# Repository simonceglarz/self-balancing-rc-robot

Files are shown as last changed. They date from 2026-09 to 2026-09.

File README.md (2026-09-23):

# ESP32 Self-Balancing Robot

A two-wheeled self-balancing robot built around an ESP32, an IMU, and a cascaded PID control loop — with a live WiFi tuning interface and a dedicated wireless joystick controller.

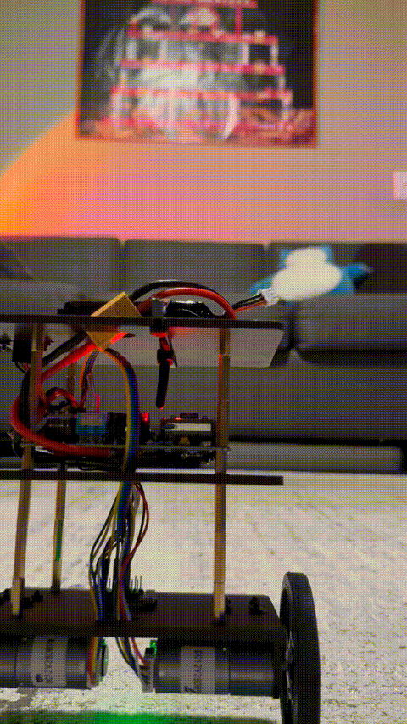
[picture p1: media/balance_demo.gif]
demo

   [Full-length demo (27s, MP4)](media/balance_full.mp4)
## Overview

This robot balances on two wheels using a complementary filter for orientation estimation and a two-loop (cascaded) PID controller: an inner loop holds the body upright, and an outer loop corrects for long-term drift by tracking wheel velocity from quadrature encoders. It can be driven and steered two ways — a phone/browser joystick served directly from the robot's own WiFi access point, or a dedicated physical ESP32 + analog-joystick controller communicating over ESP-NOW.

## Features

- **Cascaded PID control** — inner loop (angle) + outer loop (velocity/drift), tuned live rather than by reflashing
- **WiFi live-tuning webpage** — the ESP32 hosts its own access point and a WebSocket-driven page with sliders for every gain, calibration constant, and per-motor floor, plus a draggable on-screen joystick for driving
- **Physical joystick controller** — a second ESP32 reading an analog joystick, sending continuous steering data over ESP-NOW (no phone required, lower latency than WiFi)
- **Per-motor stiction compensation** — independently tunable output floors and a proportional rescale, since the two motors' real-world behavior isn't identical
- **Hysteresis-based deadband** — a Schmitt-trigger style engage/disengage threshold to suppress motor chatter at equilibrium without losing responsiveness to small corrections
- **Smoothly ramped inputs** — commanded lean/steer values slew toward their target instead of stepping instantly, avoiding derivative-kick spikes
- **OLED live telemetry** — angle, motor output, encoder-derived velocity, battery voltage, and a small tilt-indicator graphic

## Hardware

| Component | Notes |
|---|---|
| ESP32 dev board (x2) | one for the robot, one for the joystick controller |
| Adafruit LSM6DSOX | 6-axis IMU (accelerometer + gyro) |
| SSD1306 OLED (128x64, I2C) | onboard telemetry display |
| 2x DC motor + quadrature encoders | drive + odometry |
| Motor driver (dual H-bridge) | AIN1/AIN2, BIN1/BIN2 control |
| 2-axis analog joystick module | physical controller input |
| LiPo battery + voltage divider | robot power + monitoring via `analogReadMilliVolts()` |
| Buck regulator (Adafruit MPM3610, 5V) | steps the 7.4V 2S LiPo down to 5V for the ESP32 |
| Reverse-polarity protection (1N5822 Schottky) | sits ahead of the buck input, ~0.35V drop |

## Build

| | |
|---|---|
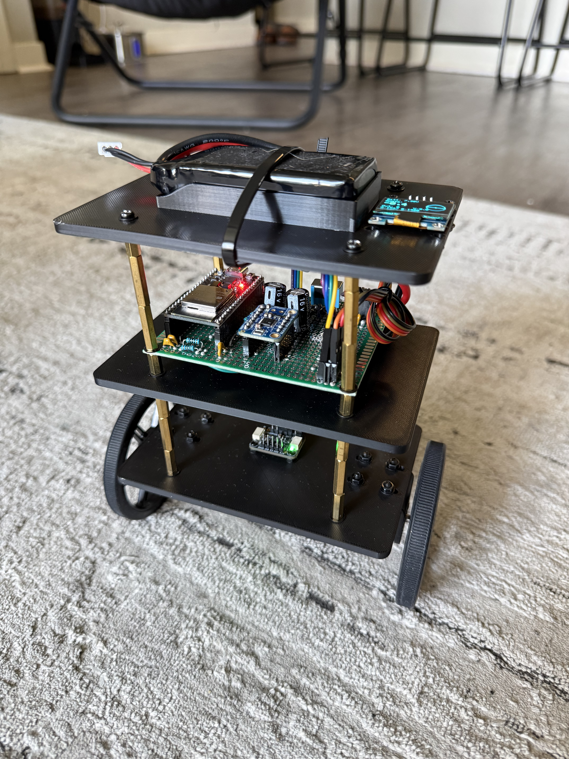
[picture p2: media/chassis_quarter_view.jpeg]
Full assembled chassis
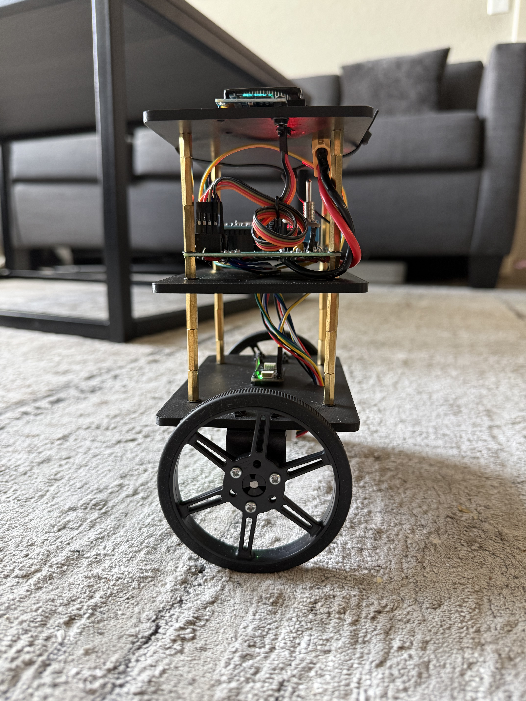
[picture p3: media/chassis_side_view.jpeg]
Inter-layer wiring detail
|  |  |
| Assembled 3-layer 3D-printed chassis — top plate carries the LiPo battery and OLED, middle plate holds the ESP32, IMU, and perfboard wiring, bottom plate mounts the motor driver. Brass standoffs separate the layers. | Rear view showing inter-layer wiring and one of the two drive wheels. |

## Architecture

```
IMU (accel + gyro) ──► complementary filter ──► angle estimate
                                                     │
                          ┌──────────────────────────┘
                          ▼
              inner loop: PID(Kp, Ki, Kd) on angle error
                          │
              outer loop: velocity/drift correction
              (encoder-derived velocity → Kp_vel/Ki_vel → shifts
               the angle setpoint to correct long-term drift)
                          │
                          ▼
        per-motor floor rescale + hysteresis deadband
                          │
                          ▼
                   motorA() / motorB() (PWM)
```

Input arrives from either the WebSocket ('J:x:y' from the webpage joystick, or discrete gain/calibration updates from the tuning sliders) or ESP-NOW (the physical joystick controller) — both write into the same `targetAngleTrim`/`steerBias` variables, so the control loop doesn't care which source is driving it.

## Power Architecture
2S LiPo (7.4V nominal, 8.4V full)
             │
             ▼
1N5822 Schottky diode (reverse-polarity protection, ~0.35V drop)
      │ 
      ▼
power node ──┬── DRV8833 VM (motors run off the unregulated battery rail)
             ├── 2× 1000µF bulk caps + 100nF ceramic → GND
             └── MPM3610 buck regulator (Vin)
                    │
                    ▼
               5V out → ESP32 5V pin
             │
             ▼
ESP32 internal LDO → 3.3V rail
	    │
┌───────────┼───────────┐
▼           ▼           ▼
IMU + OLED Encoder VCC DRV8833 SLP
   (I2C)     (must be held high or driver sleeps)

Motors draw directly off the unregulated battery rail (through the protection diode) since they don't need clean power; logic and sensors run off the regulated 5V → 3.3V chain, which does.

**Bench-verified (multimeter):**

| Measurement point | Reading |
|---|---|
| Diode cathode (post-protection) | 8.05 V |
| MPM3610 output | 5.00 V |
| ESP32 3.3V pin | 3.32 V |
| Battery rail under full motor load | 7.77 V (no sag — bulk caps holding) |

## Setup

Each firmware is its own PlatformIO project.

**Robot** (`robot/`):
1. `pio run --target upload` from within `robot/`
2. Power on, open the serial monitor (115200 baud) — it prints the WiFi AP IP and its ESP-NOW MAC address
3. Connect a phone/laptop to the `BalanceBot` AP and open `http://<AP IP>/` for the tuning page

**Controller** (`controller/`):
1. Wire the joystick module: VRx→GPIO34, VRy→GPIO35, SW→GPIO32, VCC→3.3V, GND→GND
2. Set `robotMac[]` in `controller/src/main.cpp` to the robot's printed AP MAC address
3. Confirm `WIFI_CHANNEL` matches between both projects
4. `pio run --target upload` from within `controller/`

Both projects are pinned to the same platform version (see each `platformio.ini`) — this matters, since ESP-NOW callback signatures changed between core versions and mismatched cores between the two boards can cause hard-to-diagnose link failures.

## Debugging notes / what I actually learned building this

- **Output floor destroyed proportionality.** A flat "snap any nonzero output up to the motor's stiction floor" made the controller bang-bang, not proportional, for the entire range under a few degrees of error — the majority of actual operating time. Fixed by rescaling the output range onto `[MIN_OUTPUT, MAX_OUTPUT]` per motor instead of snapping.
- **Encoder velocity math is a real kinematics problem, not an arbitrary sign choice.** Diagnosing whether `avgVelocity` should combine the two encoders by addition or subtraction meant understanding what each raw sign actually meant physically (translation vs. yaw), not just trying both and picking whichever "looked less bad." Verified empirically with a manual push test (motors disabled, print raw deltas) rather than guessing.
- **A control loop can have the wrong sign of an otherwise-correct formula.** Reversing the encoder combination made the outer loop feed real motion back into itself as *positive* feedback instead of negative — the difference between correcting drift and amplifying it into a runaway, from one flipped sign.
- **Deadbands need hysteresis, not a single threshold.** A flat deadband still has exactly one crossing point, and standing-still equilibrium sits right on top of it — sensor noise flickering across that single threshold was the actual jitter, not "too much" or "too little" deadband. A two-threshold (engage/disengage) hysteresis fixed it structurally instead of by tuning a magic number.
- **A hard on/off switch in a control loop creates a real discontinuity.** Suppressing the outer loop during a turn (to stop it reacting to a turn-induced phantom velocity reading) fixed the turn-tipping, but re-enabling it instantly the moment steering stopped caused a visible jerk — full-strength correction plus whatever stale value existed applied in a single tick. Replaced with a ramped suppression factor.

## Known limitations / open items

- `ANGLE_TRIM_DEG` (the sensor-to-mechanical zero offset) drifts somewhat run-to-run; auto-calibration was considered but not implemented.
- Turning still relies on suppressing the outer loop rather than a from-first-principles kinematic decoupling of translation and rotation.
- No IMU cross-axis leakage compensation (untested whether it's actually present on this build).

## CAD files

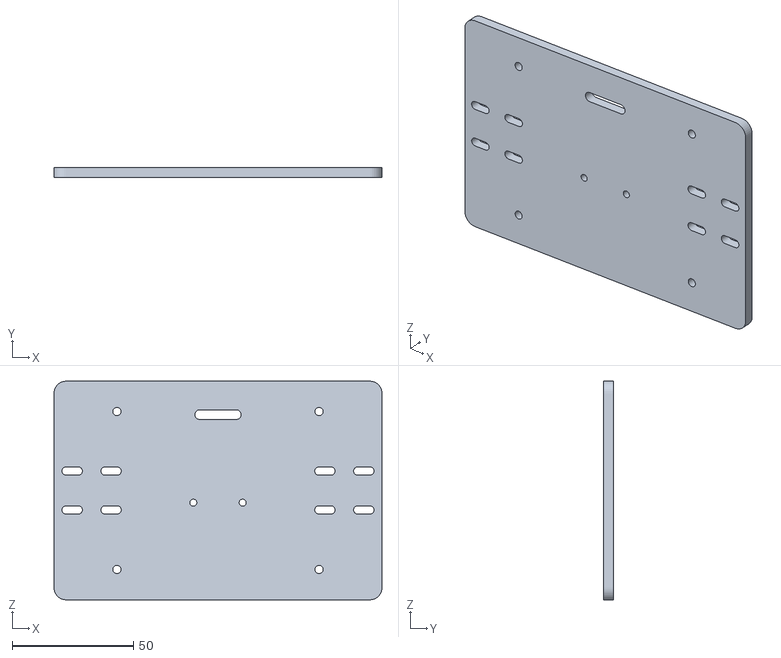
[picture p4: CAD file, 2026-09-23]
cad/chassis/bottom_plate.stl
135.0 x 4.00 x 90.0

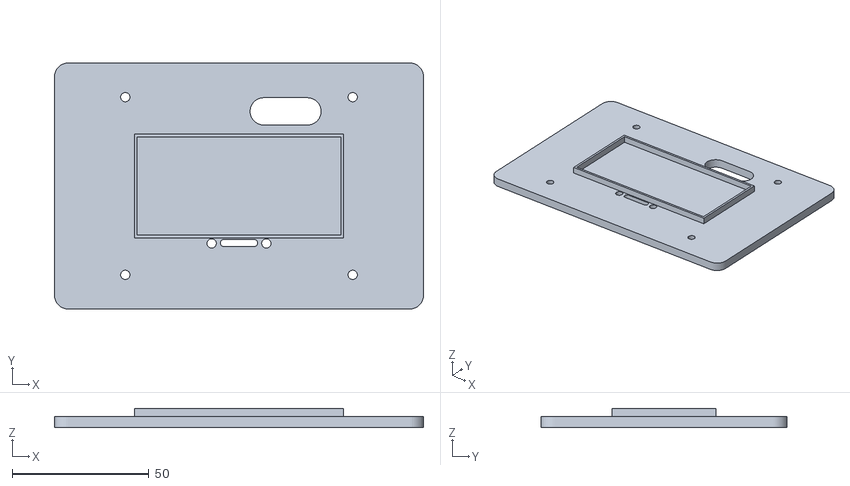
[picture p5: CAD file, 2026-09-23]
cad/chassis/top_plate_21552611.stl
135.0 x 90.0 x 7.00

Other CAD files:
cad/chassis/middle_plate.stl

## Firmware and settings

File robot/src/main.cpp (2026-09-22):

#include <Arduino.h>
#include <Wire.h>
#include <Adafruit_LSM6DSOX.h>
#include <Adafruit_SSD1306.h>
#include <Adafruit_GFX.h>
#include <WiFi.h>
#include <esp_now.h>
#include <ESPAsyncWebServer.h>

// =================== Pin map ===================
// GPIO19 = SDA, GPIO18 = SCL (confirmed against physical wiring).
#define SDA_PIN 19
#define SCL_PIN 18

// Motor driver — AIN1/AIN2 control Motor A, BIN1/BIN2 control Motor B.
#define AIN1 26
#define AIN2 32
#define BIN1 25
#define BIN2 33

// NOTE: arduino-esp32 core 3.0+ removed manual channel numbers —
// ledcAttach() below assigns a channel automatically per pin.

// Encoders — A-channel pins are the interrupt pins.
// GPIO 34/35 are input-only (no internal pull-up) — fine here,
// encoders are pure inputs. Can't be used for motor drive.
#define ENC_A1 27   // Motor A channel A
#define ENC_B1 14   // Motor A channel B
#define ENC_A2 34   // Motor B channel A
#define ENC_B2 35   // Motor B channel B

#define ENABLE_BATTERY_MONITOR 1
#if ENABLE_BATTERY_MONITOR
#define VBAT_PIN 36   // ADC1 — required, ADC2 dies when WiFi is active
const float VBAT_DIVIDER_RATIO = (100000.0 + 47000.0) / 47000.0; // 3.128
const float VBAT_CUTOFF = 6.6;
float lastVbat = 0.0;   // updated once/sec in loop(), read by the OLED block
#endif

// =================== Direction flags ===================
// Unknowns per project notes: mirror-mounted motors likely need one
// side's wires (or this flag) flipped; encoder sign is unverified
// until wheels actually turn. Flip these booleans after your first
// power-on test rather than rewiring or rewriting logic.
const bool INVERT_MOTOR_A = false;
const bool INVERT_MOTOR_B = true;   // confirmed via motor/encoder test — wheels now spin correctly
const bool INVERT_ENC_A   = false;
const bool INVERT_ENC_B   = false;

// Set to 1, flash, watch which physical wheel moves during each phase.
// Set back to 0 once you've identified A vs B and set the INVERT flags
// above — then reflash for real balancing.
#define RUN_MOTOR_ENCODER_TEST 0

// Set to 1 for a dead-simple sanity check: both motors spin together
// whenever the IMU detects real rotation, no matter which way the
// board is physically mounted. Good first test when you're not sure
// if motors OR the gyro are the actual problem.
#define RUN_BASIC_MOTOR_GYRO_TEST 0

// Set to 1 to run a bare I2C bus scan instead of normal setup — useful
// for diagnosing wiring without touching lib_deps/includes at all,
// since this reuses the exact dependency set that already builds fine.
#define RUN_I2C_SCANNER 0

#if RUN_I2C_SCANNER
void runI2CScanner() {
    Serial.println("I2C Scanner starting...");
    while (1) {
        byte count = 0;
        for (byte addr = 1; addr < 127; addr++) {
            Wire.beginTransmission(addr);
            byte error = Wire.endTransmission();
            if (error == 0) {
                Serial.print("Device found at address 0x");
                if (addr < 16) Serial.print("0");
                Serial.println(addr, HEX);
                count++;
            }
        }
        if (count == 0) Serial.println("No I2C devices found");
        else { Serial.print(count); Serial.println(" device(s) found"); }
        delay(3000);
    }
}
#endif

// =================== Objects ===================
Adafruit_LSM6DSOX sox;                          // IMU driver instance — talks to the
                                                 // physical sensor over I2C once Wire.begin() runs
Adafruit_SSD1306 display(128, 64, &Wire, -1);   // OLED driver — 128x64 px, shares the I2C bus
                                                 // with the IMU (-1 = no dedicated reset pin wired)

// Network name/password the ESP32 broadcasts. Since we're in AP mode,
// the ESP32 *is* the WiFi network — your phone connects to "BalanceBot"
// directly rather than both devices joining your home router.
const char* AP_SSID = "BalanceBot";
const char* AP_PASS = "tuning123";   // WPA2 requires 8+ characters minimum

// ESP-NOW (the physical joystick controller) and the AP (the tuning
// webpage) share the same radio, so they must agree on a channel — the
// controller firmware hardcodes this same value. If ESP-NOW packets
// silently never arrive, mismatched channel is the first thing to check.
const int WIFI_CHANNEL = 1;

AsyncWebServer server(80);
AsyncWebSocket ws("/ws");

// Must match the controller's JoyPacket struct byte-for-byte — ESP-NOW
// has no schema, it just copies raw bytes.
typedef struct {
    float x;   // -1 (left) .. +1 (right)
    float y;   // -1 (back) .. +1 (forward)
} JoyPacket;

// Shared with the webpage's 'J' WebSocket handler below, so both input
// sources command the same maximum lean/turn.
const float JOY_MAX_TRIM_DEG = 3.0;   // matches old FWD/BACK magnitude
const float JOY_MAX_STEER    = 30.0;  // matches old L/R magnitude

// =================== Live-tunable gains (WiFi) ===================
volatile float Kp = 38.0;
volatile float Ki = 0.7;
volatile float Kd = 0.4;
volatile float targetAngleTrim = 0.0;   // "goal" value set instantly by F/B commands —
                                         // the loop ramps toward this via
                                         // targetAngleTrimSmoothed rather than using
                                         // it directly, to avoid a derivative-kick step.
volatile float steerBias = 0.0;         // "goal" value set instantly by L/R commands —
                                         // same ramping treatment via steerBiasSmoothed.

// =================== Outer loop gains (WiFi-tunable via V/W) ===================
volatile float Kp_vel = 0.12;
volatile float Ki_vel = 0.003;

// =================== Filter / control state ===================
const float alpha = 0.98;

// Corrects for the IMU's zero-angle not lining up with the robot's true
// mechanical balance point (from mounting tilt, CoG offset, or both).
// Determine by trial and error: nudge this value up/down and re-test
// forward vs backward reaction thresholds until they're symmetric.
// Sign convention: if forward tilts react at SMALLER angles than
// backward tilts (as observed), try a small POSITIVE value first.
volatile float ANGLE_TRIM_DEG = -2.2;  // Tune live via the WiFi slider.
                             // The outer velocity loop can mask a wide
                             // range of trim error by continuously
                             // creeping to hold position, so "it balances"
                             // isn't proof a given value is correct —
                             // watch for steady creep in one direction
                             // at rest as the real symmetry check.

float angle = 0.0;
float lastAngle = 0.0;      // for derivative-on-measurement — see loop()
float gyroBias = 0.0;
float angleErrorIntegral = 0.0;
const float INTEGRAL_CLAMP = 100.0;
float velIntegral = 0.0;
const int MAX_OUTPUT = 255;

// Per-motor stiction floors — NOT assumed equal. Testing found motor A's
// physical wheel needs more duty to start turning than motor B's at all
// (at MIN=147, only B moved) — a single shared floor can't be correct for
// both without either stalling A or overdriving B. Tune live via WiFi.
volatile int MIN_OUTPUT_A = 146;
volatile int MIN_OUTPUT_B = 146;

// Per-motor output scale, applied across the WHOLE output range (not just
// near the floor) — corrects one motor consistently out-turning the other
// even away from the stiction region (observed: countB always ends up
// higher than countA over a run). Start both at 1.0 and nudge the FASTER
// motor's scale down while watching countA/-countB converge on the OLED.
volatile float MOTOR_A_SCALE = 1.0;
volatile float MOTOR_B_SCALE = 1.0;

const float FALL_CUTOFF_DEG = 45.0;

// Exponential-moving-average state for the encoder-derived velocity —
// see avgVelocityFiltered below. 0.1 is a starting guess, not a derived
// value: raise it (closer to 1.0) for less smoothing/more responsiveness,
// lower it for more smoothing if the outer loop still looks jumpy.
const float VEL_FILTER_ALPHA = 0.1;

// Max age, in seconds, that a single loop iteration's dt is allowed to
// have before being clamped. Without this, a loop iteration delayed by
// WiFi/WebSocket servicing (a genuinely occasional ESP32 async-server
// hiccup) produces one abnormally large dt, which inflates the integral
// term (error * dt) and shrinks the derivative denominator in the same
// tick — a plausible cause of the brief "controls give out" moments.
const float MAX_DT = 0.02;   // 20ms — 2x the normal ~10ms tick

// How fast targetAngleTrim/steerBias ramp toward their commanded value
// per second, instead of jumping instantly. Prevents the FWD/BACK/LEFT/
// RIGHT buttons from causing a one-tick derivative-kick-style spike and
// the overshoot/tipping that comes with it. Starting guesses — raise for
// snappier response, lower if it still feels like it overshoots.
const float TRIM_SLEW_PER_SEC  = 12.0;  // deg/sec
const float STEER_SLEW_PER_SEC = 80.0;  // units/sec (same units as steerBias)

// =================== Encoder state ===================
volatile long countA = 0;
volatile long countB = 0;
long lastCountA = 0, lastCountB = 0;

void IRAM_ATTR encA_ISR() {
    bool state = digitalRead(ENC_A1) == digitalRead(ENC_B1);
    if (INVERT_ENC_A) state = !state;
    if (state) countA++; else countA--;
}
void IRAM_ATTR encB_ISR() {
    bool state = digitalRead(ENC_A2) == digitalRead(ENC_B2);
    if (INVERT_ENC_B) state = !state;
    if (state) countB++; else countB--;
}

// =================== Motor drive ===================
void motorA(int speed) {
    if (INVERT_MOTOR_A) speed = -speed;
    speed = constrain(speed, -255, 255);
    if (speed >= 0) { ledcWrite(AIN1, speed); ledcWrite(AIN2, 0); }
    else            { ledcWrite(AIN1, 0); ledcWrite(AIN2, -speed); }
}
void motorB(int speed) {
    if (INVERT_MOTOR_B) speed = -speed;
    speed = constrain(speed, -255, 255);
    if (speed >= 0) { ledcWrite(BIN1, speed); ledcWrite(BIN2, 0); }
    else            { ledcWrite(BIN1, 0); ledcWrite(BIN2, -speed); }
}

// =================== Motor/Encoder identification test ===================
// Defined HERE (after motorA/motorB/countA/countB), not earlier — it
// references all of them. The actual CALL that runs this lives in
// setup(), further down.
#if RUN_MOTOR_ENCODER_TEST
void runMotorEncoderTest() {
    Serial.println("=== MOTOR/ENCODER TEST ===");
    Serial.println("Watch which physical wheel moves in each phase.");
    delay(2000);

    Serial.println("Testing Motor A (forward command)...");
    motorA(150);
    for (int i = 0; i < 15; i++) {
        Serial.print("  countA: "); Serial.println(countA);
        delay(100);
    }
    motorA(0);
    delay(1000);

    Serial.println("Testing Motor B (forward command)...");
    motorB(150);
    for (int i = 0; i < 15; i++) {
        Serial.print("  countB: "); Serial.println(countB);
        delay(100);
    }
    motorB(0);

    Serial.println("=== TEST COMPLETE ===");
    Serial.println("Whichever wheel moved during 'Motor A' phase IS Motor A.");
    Serial.println("If countA/countB didn't increase during its own phase,");
    Serial.println("that encoder's INVERT flag or wiring needs checking.");
    while (1) delay(1000);  // halt here — never falls through to balancing
}
#endif
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
void loop() {
    static unsigned long lastTime = 0;
    static unsigned long lastDisplay = 0;
    static unsigned long lastTelemetry = 0;
    static float avgVelocityFiltered = 0.0;      // smoothed encoder velocity — see VEL_FILTER_ALPHA
    static float targetAngleTrimSmoothed = 0.0;  // ramped toward targetAngleTrim — see TRIM_SLEW_PER_SEC
    static float steerBiasSmoothed = 0.0;        // ramped toward steerBias — see STEER_SLEW_PER_SEC
    static bool motorEngaged = false;            // hysteresis deadband state — see below
    static float turnSuppress = 0.0;             // 0 = full Kp_vel authority, 1 = fully suppressed — see below

    unsigned long now = millis();
    if (now - lastTime < 10) return;
    float dt = (now - lastTime) / 1000.0;
    lastTime = now;

    // Guard against a delayed loop iteration (e.g. WiFi/WebSocket
    // servicing) producing one abnormally large dt, which would
    // otherwise inflate the integral term and shrink the derivative
    // denominator in the same tick — see MAX_DT comment above.
    if (dt > MAX_DT) dt = MAX_DT;

    sensors_event_t accel, gyro, temp;
    sox.getEvent(&accel, &gyro, &temp);

    float accelAngle = atan2(accel.acceleration.y,
                             accel.acceleration.z) * 180.0 / PI - ANGLE_TRIM_DEG;
    float gyroRate = (gyro.gyro.x * 180.0 / PI) - gyroBias;

    angle = alpha * (angle + gyroRate * dt) + (1.0 - alpha) * accelAngle;

    // Ramp the commanded trim/steer toward their target values instead
    // of jumping instantly — avoids the derivative-kick-style spike a
    // step change would otherwise cause (see loop() notes below).
    float trimStep = TRIM_SLEW_PER_SEC * dt;
    if (targetAngleTrimSmoothed < targetAngleTrim) {
        targetAngleTrimSmoothed = min(targetAngleTrimSmoothed + trimStep, (float)targetAngleTrim);
    } else if (targetAngleTrimSmoothed > targetAngleTrim) {
        targetAngleTrimSmoothed = max(targetAngleTrimSmoothed - trimStep, (float)targetAngleTrim);
    }
    float steerStep = STEER_SLEW_PER_SEC * dt;
    if (steerBiasSmoothed < steerBias) {
        steerBiasSmoothed = min(steerBiasSmoothed + steerStep, (float)steerBias);
    } else if (steerBiasSmoothed > steerBias) {
        steerBiasSmoothed = max(steerBiasSmoothed - steerStep, (float)steerBias);
    }

    bool fallen = fabs(angle) > FALL_CUTOFF_DEG;
    int output = 0;
    // Hoisted out of the else-block below (rather than declared with
    // "float" inside it) so the OLED block further down can read the
    // latest value regardless of which branch ran this iteration.
    float avgVelocity = 0.0;

    if (fallen) {
        motorA(0); motorB(0);
        angleErrorIntegral = 0;
        velIntegral = 0;
        avgVelocityFiltered = 0.0;        // reset smoothing too — don't carry stale
                                           // velocity history into the next stand-up
        targetAngleTrimSmoothed = 0.0;    // don't carry a mid-ramp command into the
        steerBiasSmoothed = 0.0;          // next stand-up either — start neutral
        motorEngaged = false;             // start disengaged on the next stand-up too
        turnSuppress = 0.0;                // don't carry a mid-turn suppression level into the next stand-up
        countA = 0; countB = 0; lastCountA = 0; lastCountB = 0;
    } else {
        long dCountA = countA - lastCountA;
        long dCountB = countB - lastCountB;
        lastCountA = countA; lastCountB = countB;

        // Reverted to addition after both subtraction sign orders caused
        // an immediate runaway / total loss of balance on real hardware.
        // Kinematically, subtraction is arguably "more correct" (it
        // isolates real translation instead of canceling it), but that
        // also means it stops canceling the wheel movement the robot
        // does constantly just to hold itself up — a signal far larger
        // than Kp_vel/Ki_vel were ever tuned against. Addition is the
        // form that has actually balanced on this robot; don't change
        // it again without also re-tuning Kp_vel/Ki_vel from scratch
        // against the new signal scale.
        avgVelocity = ((dCountA + dCountB) / 2.0) / dt;

        // Raw avgVelocity is extremely noisy at this loop rate: dt is
        // ~10ms, so a single encoder-tick difference between iterations
        // (ordinary quantization noise, not real motion) swings the raw
        // value by tens of counts/sec. Smooth it with an EMA before it
        // feeds the outer loop, so tick-to-tick jitter doesn't get
        // interpreted as real velocity and jerk the setpoint around.
        avgVelocityFiltered = (1.0 - VEL_FILTER_ALPHA) * avgVelocityFiltered
                             + VEL_FILTER_ALPHA * avgVelocity;

        // Suppress the outer loop's proportional term while a turn is
        // actively commanded — same reasoning as before (during a turn,
        // imperfect wheel-speed matching can show up as a nonzero
        // "phantom" avgVelocity that isn't real drift, and at Kp_vel this
        // high that blip becomes a real spurious setpoint shift). BUT this
        // is now a smoothly ramped suppression factor instead of a hard
        // on/off switch — the old version snapped Kp_vel's full authority
        // back on in a single tick the instant steering ended, which is
        // exactly what caused the forward jerk right after a turn: full
        // Kp_vel plus whatever velocity reading existed at that exact
        // instant, applied all at once. Ramping it over TURN_SUPPRESS_SLEW
        // means there's no instant to re-apply a full-strength correction.
        float turnSuppressTarget = (fabs(steerBiasSmoothed) > 1.0) ? 1.0 : 0.0;
        const float TURN_SUPPRESS_SLEW = 3.0;   // per second — ~0.33s to fully engage/disengage
        if (turnSuppress < turnSuppressTarget) {
            turnSuppress = min(turnSuppress + TURN_SUPPRESS_SLEW * dt, turnSuppressTarget);
        } else if (turnSuppress > turnSuppressTarget) {
            turnSuppress = max(turnSuppress - TURN_SUPPRESS_SLEW * dt, turnSuppressTarget);
        }
        // Also taper how much the integral accumulates during a turn,
        // rather than freezing it outright — avoids a second discontinuity
        // when accumulation switches back on.
        velIntegral += avgVelocityFiltered * dt * (1.0 - turnSuppress);
        velIntegral = constrain(velIntegral, -500, 500);
        float velCorrection = -((Kp_vel * (1.0 - turnSuppress)) * avgVelocityFiltered
                               + Ki_vel * velIntegral);

        float setpoint = targetAngleTrimSmoothed + velCorrection;
        float error = setpoint - angle;

        angleErrorIntegral += error * dt;
        angleErrorIntegral = constrain(angleErrorIntegral,
                                        -INTEGRAL_CLAMP, INTEGRAL_CLAMP);

        // Derivative-on-measurement: based on the angle itself, not on
        // the error. A step change in setpoint (from targetAngleTrim,
        // via FWD/BACK) no longer causes a one-tick derivative spike —
        // it only reacts to how fast the robot itself is actually
        // tilting. Combined with ramping the setpoint above, this is
        // what should fix the FWD/BACK overshoot and LEFT/RIGHT tipping.
        float derivative = -(angle - lastAngle) / dt;
        lastAngle = angle;

        output = (int)(Kp * error + Ki * angleErrorIntegral + Kd * derivative);
        output = constrain(output, -MAX_OUTPUT, MAX_OUTPUT);

        // Hysteresis (Schmitt-trigger) deadband instead of a single flat
        // threshold. A flat deadband still has ONE crossing point, and
        // right at standing-still equilibrium, sensor noise flickers the
        // raw output back and forth across it many times a second — each
        // crossing snaps output from 0 straight to ~MIN_OUTPUT (~148),
        // which is the actual jitter, not just "small output". Requiring
        // a HIGHER value to engage than to disengage means noise sitting
        // near the boundary can't keep re-triggering that jump — output
        // has to clearly commit to one side before the motor turns on,
        // and clearly fall off before it turns back off.
        const int ENGAGE_THRESHOLD    = 8;  // must exceed this to turn ON
        const int DISENGAGE_THRESHOLD = 3;  // must drop below this to turn OFF
        if (!motorEngaged && abs(output) > ENGAGE_THRESHOLD)    motorEngaged = true;
        if (motorEngaged  && abs(output) < DISENGAGE_THRESHOLD) motorEngaged = false;
        if (!motorEngaged) output = 0;
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

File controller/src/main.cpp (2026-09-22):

#include <Arduino.h>
#include <esp_now.h>
#include <esp_wifi.h>
#include <WiFi.h>

// =================== Pin map ===================
#define VRX_PIN 34   // ADC1 — input-only pin, fine for analog read
#define VRY_PIN 35   // ADC1 — input-only pin, fine for analog read
#define SW_PIN  32   // digital, has internal pull-up available

// =================== Robot's ESP-NOW address ===================
// Fill this in with the ROBOT's AP MAC address, not its station MAC —
// the robot runs WiFi.softAP(), so the address you want is what
// WiFi.softAPmacAddress() prints on ITS serial monitor at boot
// (main.cpp now prints this — look for "Robot AP MAC:" in its Serial
// output). Format: 6 bytes, comma-separated, 0x-prefixed.
uint8_t robotMac[] = {0xB0, 0xCB, 0xD8, 0xCD, 0x8B, 0xA1};

// Must match the robot's AP channel (see WIFI_CHANNEL in main.cpp).
// ESP-NOW packets are only received if sender and receiver agree on
// the channel — this is the single most common reason ESP-NOW "just
// doesn't work" on a first attempt.
const int WIFI_CHANNEL = 1;

// =================== Joystick calibration ===================
int centerX = 2048, centerY = 2048;   // overwritten by auto-calibration in setup()
const int DEADZONE = 150;             // ADC counts around center treated as exactly 0 —
                                       // cheap joysticks don't rest dead-center or return
                                       // to the exact same spot every time
const int ADC_MAX = 4095;             // ESP32 ADC is 12-bit

// Packet layout MUST match the robot's JoyPacket struct exactly —
// ESP-NOW just copies raw bytes, there's no schema negotiation.
typedef struct {
    float x;   // -1 (left) .. +1 (right)
    float y;   // -1 (back) .. +1 (forward)
} JoyPacket;

void onDataSent(const uint8_t *mac_addr, esp_now_send_status_t status) {
    // Optional — uncomment while debugging link issues, noisy otherwise
    // Serial.println(status == ESP_NOW_SEND_SUCCESS ? "sent OK" : "send FAILED");
}

// Maps a raw ADC reading to -1..1, treating DEADZONE counts around the
// calibrated center as exactly 0, then scaling the remaining travel on
// each side independently (cheap joysticks are rarely symmetric around
// center).
float normalize(int raw, int center) {
    int delta = raw - center;
    if (abs(delta) < DEADZONE) return 0.0;
    if (delta > 0) return (float)(delta - DEADZONE) / (float)(ADC_MAX - center - DEADZONE);
    else           return (float)(delta + DEADZONE) / (float)(center - DEADZONE);
}

void setup() {
    Serial.begin(115200);
    pinMode(SW_PIN, INPUT_PULLUP);

    WiFi.mode(WIFI_STA);
    // Lock to the robot's channel BEFORE esp_now_init() — WiFi.mode()
    // alone doesn't guarantee a channel if this board isn't also
    // joining an AP.
    esp_wifi_set_channel(WIFI_CHANNEL, WIFI_SECOND_CHAN_NONE);

    if (esp_now_init() != ESP_OK) {
        Serial.println("ESP-NOW init failed");
        while (1) delay(1000);
    }
    esp_now_register_send_cb(onDataSent);

    esp_now_peer_info_t peerInfo = {};
    memcpy(peerInfo.peer_addr, robotMac, 6);
    peerInfo.channel = WIFI_CHANNEL;
    peerInfo.encrypt = false;
    if (esp_now_add_peer(&peerInfo) != ESP_OK) {
        Serial.println("Failed to add peer — check robotMac[] is correct");
        while (1) delay(1000);
    }

    // Auto-center calibration: assumes the stick is at rest (untouched)
    // for this half-second at power-on. Re-flash or power-cycle if you
    // accidentally touched it during this window and centering feels off.
    Serial.println("Calibrating center — don't touch the stick...");
    long sumX = 0, sumY = 0;
    const int CAL_SAMPLES = 50;
    for (int i = 0; i < CAL_SAMPLES; i++) {
        sumX += analogRead(VRX_PIN);
        sumY += analogRead(VRY_PIN);
        delay(10);
    }
    centerX = sumX / CAL_SAMPLES;
    centerY = sumY / CAL_SAMPLES;
    Serial.print("Center: "); Serial.print(centerX); Serial.print(", "); Serial.println(centerY);
    Serial.println("Ready.");
}

void loop() {
    int rawX = analogRead(VRX_PIN);
    int rawY = analogRead(VRY_PIN);

    JoyPacket packet;
    packet.x = constrain(normalize(rawX, centerX), -1.0, 1.0);
    packet.y = constrain(normalize(rawY, centerY), -1.0, 1.0);

    esp_now_send(robotMac, (uint8_t *)&packet, sizeof(packet));

    delay(50);   // ~20Hz — matches the webpage joystick's own send throttle
}

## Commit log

2026-09-23 Add chassis STLs and KiCad schematic
    [bottom_plate.stl, middle_plate.stl, top_plate_21552611.stl]
2026-09-23 Add chassis build photos
2026-09-23 Document power architecture and buck regulator
2026-10-12 Add rev 1 PCB: KiCad project, Gerbers, renders and write-up
2026-10-12 Update front PCB render
2026-10-22 PCB rev 1: pin map (motors 32/33/26/25, encoders A=34/35 B=27/14), OLED on Wire1 (21/22), two-bus I2C scanner; live-tunable fall cutoff (55 deg default) with dashboard slider; telemetry sent while fa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
